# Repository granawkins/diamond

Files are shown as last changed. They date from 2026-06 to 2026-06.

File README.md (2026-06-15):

# Diamond

Diamond is a Raspberry Pi rover named after Neal Stephenson's *The Diamond Age*.
The current build is a four-motor, skid-steer rover in the `rover-v2` printed
body, controlled by an Xbox Wireless Controller.

The abandoned quadruped code and servo UI have been removed. The MG90/SG90 leg
approach was not strong enough once the battery and Pi hardware were installed,
so the project is now wheeled.

## Current Hardware

- Raspberry Pi powered from a Waveshare UPS HAT.
- Four DC gear motors, two on each side.
- Two L298 H-bridge boards, one per side.
- Separate Li-ion/LiPo motor battery with common ground to the Pi.
- Xbox Wireless Controller for live driving.
- `rover-v2` CAD files for the current 3D-printed body.

## Wiring

Do not power the motors from the Pi, UPS HAT, or GPIO header. The Pi and motors
use separate power domains with a shared ground.

```text
                 Brain power domain

  UPS HAT battery
       |
       v
  Waveshare UPS HAT
       |
       | 5V through HAT/header
       v
  Raspberry Pi

                 Motor power domain

  Motor battery positive
       |
       +----> Left L298 +12V / VMS
       |
       +----> Right L298 +12V / VMS

  Motor battery negative
       |
       +----> Left L298 GND
       |
       +----> Right L298 GND
       |
       +----> Raspberry Pi GND, physical pin 6
```

Only the grounds are tied together. Do not tie the motor battery positive rail to
the Pi 5V rail.

Use one L298 board for the left side and one for the right side.

```text
Top view

        front

   left L298 board              right L298 board
   OUT1/OUT2 -> left front      OUT1/OUT2 -> right front
   OUT3/OUT4 -> left rear       OUT3/OUT4 -> right rear

        rear
```

Each L298 board has two channels. Both channels on the same side are driven from
the same three GPIO signals so the front and rear motors on that side always move
together.

## GPIO

BCM numbering is used in code.

| Signal | Pi BCM | Pi physical pin | L298 connection |
|---|---|---|---|
| Left PWM | GPIO12 | pin 32 | Left ENA and ENB |
| Left forward | GPIO5 | pin 29 | Left IN1 and IN3 |
| Left reverse | GPIO6 | pin 31 | Left IN2 and IN4 |
| Right PWM | GPIO13 | pin 33 | Right ENA and ENB |
| Right forward | GPIO20 | pin 38 | Right IN1 and IN3 |
| Right reverse | GPIO16 | pin 36 | Right IN2 and IN4 |
| Ground | GND | pin 6 | Both L298 GND rails |

If the L298 boards have ENA/ENB jumpers installed, remove those jumpers so the Pi
can control speed with PWM. Then connect:

- Pi GPIO12 to both `ENA` and `ENB` on the left L298.
- Pi GPIO13 to both `ENA` and `ENB` on the right L298.

GPIO21 is reserved for I2S speaker audio and should not be used for motor
control.

## Speaker Audio

The MAX98357A I2S amplifier uses the Pi's standard I2S playback pins.

| MAX98357A | Pi BCM | Pi physical pin |
|---|---|---|
| BCLK | GPIO18 | pin 12 |
| LRC / LRCLK | GPIO19 | pin 35 |
| DIN | GPIO21 | pin 40 |
| VIN | 5V | pin 2 or 4 |
| GND | GND | any ground |

The runtime audio device is:

```text
plughw:CARD=MAX98357A,DEV=0
```

If a motor spins backward during testing, swap that motor's two output wires at
the L298 board. Keep the GPIO mapping unchanged.

## Motor Leads

Some gear motors include two heavy motor leads plus four encoder leads. For the
first motor test, only the motor leads connect to the L298 outputs.

Typical color mapping:

| Motor wire | First-test use | Notes |
|---|---|---|
| Red | L298 motor output | Usually motor positive |
| Black | L298 motor output | Usually motor negative |
| Yellow | leave disconnected | Encoder channel A on many motors |
| Green | leave disconnected | Encoder channel B or encoder ground on some variants |
| Blue | leave disconnected | Encoder power or encoder signal on some variants |
| White | leave disconnected | Encoder power, ground, or signal on some variants |

Do not guess the encoder wiring from color alone before powering it. The four
encoder wires are low-current logic wires and should not be connected to L298
outputs or motor power.

## L298 Power Notes

Most L298N modules have a `5V_EN` or `5V enable` jumper:

- With motor battery voltage on the `+12V`/`VMS` terminal, the board usually
  powers its own 5V logic regulator when the jumper is installed.
- Do not connect the L298 board's `5V` terminal to the Pi 5V pin during bring-up.
- If the exact L298 board requires an external 5V logic input, confirm that from
  the board silkscreen or listing before wiring the Pi 5V rail to it.

The Pi's 3.3V GPIO control signals are normally accepted by L298N input pins.

## Wiring Checklist

1. Power the Pi from the Waveshare UPS HAT only.
2. Leave the motor battery disconnected while wiring GPIO.
3. Wire Pi GND pin 6 to both L298 `GND` terminals.
4. Wire the left board GPIO signals.
5. Wire the right board GPIO signals.
6. Wire the four motors to the L298 outputs.
7. Put the rover on blocks so the wheels cannot touch the table or floor.
8. Connect motor battery positive to both L298 `+12V`/`VMS` terminals.
9. Connect motor battery negative to both L298 `GND` terminals.
10. Run `diamond.py` at a conservative speed and verify direction.

## Setup

```bash
python3 -m venv .venv
source .venv/bin/activate
pip install -r requirements.txt
cd webapp
npm install
```

## Web Control

The lightweight web page lives in [index.html](index.html) and is served by
[diamond.py](diamond.py). `diamond.py` is the single hardware owner and also
exposes HTTP endpoints for component testing.

```bash
.venv/bin/python diamond.py --max-speed 1.00
```

By default it listens on `0.0.0.0:3030`.

## Xbox Control

```bash
.venv/bin/python diamond.py --max-speed 1.00
```

The left stick maps to mixed drive: up/down is throttle, left/right is steering.
Put the rover on blocks for first tests. Use a lower `--max-speed` manually if
wiring or direction needs to be re-verified.

## Future Direction

Next major work is vision, audio input/output, and connecting the rover to an LLM,
probably through an API or over Tailscale to a local service running on a desktop
GPU.

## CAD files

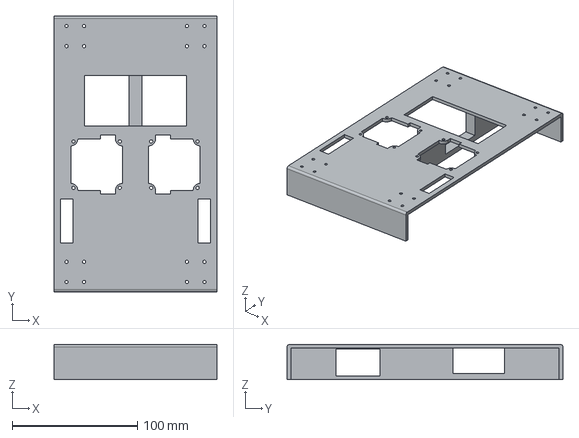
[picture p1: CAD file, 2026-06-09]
rover-v2-Body.3mf.step
130.0 x 220.0 x 28.0 mm

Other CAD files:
rover-v2.FCStd

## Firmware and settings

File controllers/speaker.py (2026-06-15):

import argparse
import math
import tempfile
import subprocess
import wave
from pathlib import Path


"""
Persistent Raspberry Pi setup for the MAX98357A I2S amplifier lives in
/boot/firmware/config.txt:

    dtparam=i2s=on
    dtoverlay=max98357a

After changing those lines, reboot before relying on the speaker after startup.
"""

DEFAULT_DEVICE = "plughw:CARD=MAX98357A,DEV=0"
DEFAULT_FREQUENCY = 880
DEFAULT_SECONDS = 0.25
DEFAULT_VOLUME = 0.10
DEFAULT_RATE = 48000


def list_speakers():
    """Return ALSA playback device listing text from aplay."""

    result = subprocess.run(
        ["aplay", "-l"],
        check=True,
        capture_output=True,
        text=True,
    )
    return result.stdout.strip()


def play_file(path, device=DEFAULT_DEVICE):
    """Play an audio file through the MAX98357A speaker output."""

    audio_path = Path(path)
    subprocess.run(["aplay", "-D", device, str(audio_path)], check=True)


def clamp(value, minimum=0, maximum=1):
    return max(minimum, min(maximum, value))


def write_tone(path, frequency=DEFAULT_FREQUENCY, seconds=DEFAULT_SECONDS, volume=DEFAULT_VOLUME):
    duration = float(seconds)
    if duration <= 0:
        raise ValueError("seconds must be greater than 0")

    amplitude = int(32767 * clamp(float(volume)))
    frames = int(DEFAULT_RATE * duration)

    with wave.open(str(path), "wb") as output:
        output.setnchannels(1)
        output.setsampwidth(2)
        output.setframerate(DEFAULT_RATE)

        for index in range(frames):
            sample = int(amplitude * math.sin(2 * math.pi * frequency * index / DEFAULT_RATE))
            output.writeframesraw(sample.to_bytes(2, "little", signed=True))


def play_tone(
    frequency=DEFAULT_FREQUENCY,
    seconds=DEFAULT_SECONDS,
    volume=DEFAULT_VOLUME,
    device=DEFAULT_DEVICE,
):
    """Play a short sine tone through the MAX98357A speaker output."""

    with tempfile.NamedTemporaryFile(prefix="diamond-tone-", suffix=".wav", delete=True) as file:
        write_tone(file.name, frequency=frequency, seconds=seconds, volume=volume)
        play_file(file.name, device=device)


def parse_args():
    parser = argparse.ArgumentParser(
        description=(
            "Play audio through Diamond's MAX98357A I2S speaker. "
            "Import APIs: controllers.speaker.play_file(), play_tone(), list_speakers()."
        )
    )
    parser.add_argument("file", nargs="?", help="audio file to play with aplay")
    parser.add_argument("--device", default=DEFAULT_DEVICE)
    parser.add_argument("--list", action="store_true", help="list ALSA playback devices")
    parser.add_argument("--tone", action="store_true", help="play a sine tone instead of a file")
    parser.add_argument("--frequency", type=int, default=DEFAULT_FREQUENCY)
    parser.add_argument("--seconds", type=float, default=DEFAULT_SECONDS)
    parser.add_argument("--volume", type=float, default=DEFAULT_VOLUME, help="0.0 to 1.0")
    return parser.parse_args()


def main():
    args = parse_args()

    if args.list:
        print(list_speakers())
    elif args.tone or not args.file:
        play_tone(
            frequency=args.frequency,
            seconds=args.seconds,
            volume=args.volume,
            device=args.device,
        )
    else:
        play_file(args.file, device=args.device)


if __name__ == "__main__":
    main()

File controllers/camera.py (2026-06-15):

import argparse
import subprocess
from pathlib import Path

from controllers.utils import capture_path


DEFAULT_CAMERA = 0
DEFAULT_WIDTH = 1280
DEFAULT_HEIGHT = 720
DEFAULT_TIMEOUT_MS = 1000
DEFAULT_VIDEO_CODEC = "h264"


def default_image_path():
    return capture_path("image", "jpg")


def default_video_path(codec=DEFAULT_VIDEO_CODEC):
    extension = "h264" if codec == "h264" else codec
    return capture_path("video", extension)


def list_cameras():
    """Return rpicam's camera listing text."""

    result = subprocess.run(
        ["rpicam-still", "--list-cameras"],
        check=True,
        capture_output=True,
        text=True,
    )
    return result.stdout.strip()


def capture_image(
    output_path,
    camera=DEFAULT_CAMERA,
    width=DEFAULT_WIDTH,
    height=DEFAULT_HEIGHT,
    timeout_ms=DEFAULT_TIMEOUT_MS,
):
    """Capture a still image from the Raspberry Pi camera."""

    output = Path(output_path)
    output.parent.mkdir(parents=True, exist_ok=True)

    command = [
        "rpicam-still",
        "--camera",
        str(camera),
        "--width",
        str(int(width)),
        "--height",
        str(int(height)),
        "--timeout",
        str(int(timeout_ms)),
        "--output",
        str(output),
        "--nopreview",
    ]
    subprocess.run(command, check=True, timeout=(int(timeout_ms) / 1000) + 10)
    return output


def record_video(
    output_path,
    seconds=5,
    camera=DEFAULT_CAMERA,
    width=DEFAULT_WIDTH,
    height=DEFAULT_HEIGHT,
    codec=DEFAULT_VIDEO_CODEC,
):
    """Record video from the Raspberry Pi camera."""

    duration_ms = int(float(seconds) * 1000)
    if duration_ms <= 0:
        raise ValueError("seconds must be greater than 0")

    output = Path(output_path)
    output.parent.mkdir(parents=True, exist_ok=True)

    command = [
        "rpicam-vid",
        "--camera",
        str(camera),
        "--width",
        str(int(width)),
        "--height",
        str(int(height)),
        "--timeout",
        str(duration_ms),
        "--codec",
        codec,
        "--output",
        str(output),
        "--nopreview",
    ]
    subprocess.run(command, check=True, timeout=(duration_ms / 1000) + 10)
    return output


def parse_args():
    parser = argparse.ArgumentParser(
        description=(
            "Capture images or video from Diamond's Raspberry Pi camera. "
            "Import APIs: controllers.camera.capture_image(), record_video(), list_cameras()."
        )
    )
    parser.add_argument("output", nargs="?")
    parser.add_argument("--list", action="store_true", help="list detected cameras")
    parser.add_argument("--video", action="store_true", help="record video instead of a still image")
    parser.add_argument("--seconds", type=float, default=5, help="video duration")
    parser.add_argument("--camera", type=int, default=DEFAULT_CAMERA)
    parser.add_argument("--width", type=int, default=DEFAULT_WIDTH)
    parser.add_argument("--height", type=int, default=DEFAULT_HEIGHT)
    parser.add_argument("--timeout-ms", type=int, default=DEFAULT_TIMEOUT_MS, help="still capture warmup")
    parser.add_argument("--codec", default=DEFAULT_VIDEO_CODEC, help="video codec for rpicam-vid")
    return parser.parse_args()


def main():
    args = parse_args()

    if args.list:
        print(list_cameras())
        return

    if args.video:
        output_path = args.output or default_video_path(args.codec)
        output = record_video(
            output_path,
            seconds=args.seconds,
            camera=args.camera,
            width=args.width,
            height=args.height,
            codec=args.codec,
        )
        print(f"Recorded {args.seconds:g}s video to {output}")
    else:
        output_path = args.output or default_image_path()
        output = capture_image(
            output_path,
            camera=args.camera,
            width=args.width,
            height=args.height,
            timeout_ms=args.timeout_ms,
        )
        print(f"Captured image to {output}")


if __name__ == "__main__":
    main()

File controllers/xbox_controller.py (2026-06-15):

import glob
import os
import select
import subprocess
from dataclasses import dataclass, field
from time import sleep

from evdev import InputDevice, ecodes


DEFAULT_DEVICE = "/dev/input/event5"
DEFAULT_CONTROLLER_MAC = "40:8E:2C:4A:2D:2E"
LEFT_STICK_X = ecodes.ABS_X
LEFT_STICK_Y = ecodes.ABS_Y


@dataclass
class ControllerState:
    x: float = 0
    y: float = 0
    buttons: list[str] = field(default_factory=list)
    changed: bool = False


def normalize_axis(value, absinfo):
    center = (absinfo.min + absinfo.max) / 2
    span = (absinfo.max - absinfo.min) / 2

    if span <= 0:
        return 0

    return max(-1, min(1, (value - center) / span))


def apply_deadzone(value, deadzone):
    if abs(value) < deadzone:
        return 0

    scaled = (abs(value) - deadzone) / (1 - deadzone)
    return scaled if value > 0 else -scaled


def find_device(path=DEFAULT_DEVICE):
    if os.path.exists(path) and is_drive_device(path):
        return path

    for candidate in sorted(glob.glob("/dev/input/event*")):
        if is_drive_device(candidate):
            return candidate

    return None


def is_drive_device(path):
    try:
        device = InputDevice(path)
        device.absinfo(LEFT_STICK_X)
        device.absinfo(LEFT_STICK_Y)
    except OSError:
        return False

    return "xbox" in device.name.lower()


def connect_controller(mac=DEFAULT_CONTROLLER_MAC):
    try:
        subprocess.run(
            ["bluetoothctl", "connect", mac],
            check=False,
            capture_output=True,
            text=True,
            timeout=8,
        )
    except (OSError, subprocess.TimeoutExpired) as error:
        print(f"Bluetooth connect attempt failed: {error}", flush=True)


def connect_xbox_controller(
    device_path=DEFAULT_DEVICE,
    controller_mac=DEFAULT_CONTROLLER_MAC,
    deadzone=0.08,
):
    try:
        controller = XboxController(
            device_path=device_path,
            controller_mac=controller_mac,
            deadzone=deadzone,
            wait=False,
        )
    except (FileNotFoundError, OSError):
        connect_controller(controller_mac)
        raise

    print(f"Connected to {controller.name} at {controller.device_path}", flush=True)
    print("Left stick drives live. Release to center/stop.", flush=True)
    return controller


def wait_for_device(path=DEFAULT_DEVICE, controller_mac=DEFAULT_CONTROLLER_MAC):
    while True:
        device_path = find_device(path)

        if device_path:
            return device_path

        print(
            f"Waiting for Xbox controller {controller_mac}; trying Bluetooth connect",
            flush=True,
        )
        connect_controller(controller_mac)
        sleep(5)


class XboxController:
    """Xbox controller reader that owns connection and event polling."""

    def __init__(
        self,
        device_path=DEFAULT_DEVICE,
        controller_mac=DEFAULT_CONTROLLER_MAC,
        deadzone=0.08,
        wait=True,
    ):
        if not 0 <= deadzone < 1:
            raise ValueError("deadzone must be at least 0 and less than 1")

        self.device_path = (
            wait_for_device(device_path, controller_mac)
            if wait
            else find_device(device_path)
        )
        if not self.device_path:
            raise FileNotFoundError("Xbox controller drive device not found")

        self.device = InputDevice(self.device_path)
        self.deadzone = deadzone
        self.x_value = self.device.absinfo(LEFT_STICK_X).value
        self.y_value = self.device.absinfo(LEFT_STICK_Y).value
        self.state = self._state(changed=True)

    @property
    def name(self):
        return self.device.name

    def fileno(self):
        return self.device.fd

    def _state(self, buttons=None, changed=False):
        x_info = self.device.absinfo(LEFT_STICK_X)
        y_info = self.device.absinfo(LEFT_STICK_Y)
        x = apply_deadzone(normalize_axis(self.x_value, x_info), self.deadzone)
        y = apply_deadzone(-normalize_axis(self.y_value, y_info), self.deadzone)
        return ControllerState(x=x, y=y, buttons=buttons or [], changed=changed)

    def poll(self, timeout=0):
        readable, _, _ = select.select([self.device.fd], [], [], timeout)

        if not readable:
            self.state = self._state()
            return self.state

        changed = False
        buttons = []

        for event in self.device.read():
            if event.type == ecodes.EV_ABS:
                if event.code == LEFT_STICK_X:
                    self.x_value = event.value
                    changed = True
                elif event.code == LEFT_STICK_Y:
                    self.y_value = event.value
                    changed = True
            elif event.type == ecodes.EV_KEY and event.value:
                buttons.append(ecodes.KEY.get(event.code, str(event.code)))
                changed = True

        self.state = self._state(buttons=buttons, changed=changed)
        return self.state

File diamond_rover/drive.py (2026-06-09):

PINS = {
    "left": {"forward": 5, "reverse": 6, "enable": 12},
    "right": {"forward": 20, "reverse": 21, "enable": 13},
}


def clamp(value, minimum=-1, maximum=1):
    return max(minimum, min(maximum, value))


def validate_power(value, name="power"):
    power = float(value)
    if not -1 <= power <= 1:
        raise ValueError(f"{name} must be between -1 and 1")
    return power


def validate_speed(value, name="speed"):
    speed = float(value)
    if not 0 <= speed <= 1:
        raise ValueError(f"{name} must be between 0 and 1")
    return speed


def validate_seconds(value, maximum=5):
    seconds = float(value)
    if not 0 < seconds <= maximum:
        raise ValueError(f"seconds must be greater than 0 and no more than {maximum:g}")
    return seconds


def mix_differential(throttle, steering, max_speed=1):
    max_speed = validate_speed(max_speed, "max_speed")
    raw_left = float(throttle) + float(steering)
    raw_right = float(throttle) - float(steering)
    scale = max(1, abs(raw_left), abs(raw_right))

    return (
        clamp((raw_left / scale) * max_speed),
        clamp((raw_right / scale) * max_speed),
    )


class MotorSide:
    def __init__(self, forward_pin, reverse_pin, enable_pin):
        from gpiozero import Motor, PWMOutputDevice

        self.motor = Motor(forward=forward_pin, backward=reverse_pin)
        self.enable = PWMOutputDevice(enable_pin)
        self.power = None

    def move(self, power):
        power = clamp(float(power))

        if self.power is not None and abs(power - self.power) < 0.01:
            return

        self.power = power
        self.enable.value = abs(power)

        if power > 0:
            self.motor.forward()
        elif power < 0:
            self.motor.backward()
        else:
            self.motor.stop()

    def stop(self):
        self.power = 0
        self.motor.stop()
        self.enable.value = 0


class RoverDrive:
    def __init__(self, pins=PINS):
        self.left = MotorSide(
            forward_pin=pins["left"]["forward"],
            reverse_pin=pins["left"]["reverse"],
            enable_pin=pins["left"]["enable"],
        )
        self.right = MotorSide(
            forward_pin=pins["right"]["forward"],
            reverse_pin=pins["right"]["reverse"],
            enable_pin=pins["right"]["enable"],
        )

    def move(self, left_power, right_power):
        self.left.move(validate_power(left_power, "left"))
        self.right.move(validate_power(right_power, "right"))

    def move_side(self, side, power):
        if side not in ("left", "right"):
            raise ValueError("side must be left or right")

        getattr(self, side).move(validate_power(power, side))

    def stop(self):
        self.left.stop()
        self.right.stop()

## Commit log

2025-10-11 four legs
2025-10-23 remove reset servo
2025-10-24 battery percentage
2025-10-25 servo calibration
2025-10-25 apply calibration
2025-10-26 leg backend
2025-10-26 leg frontend
2026-06-09 Simplify repo around rover control
    [rover-v2-Body.3mf.step, rover-v2.FCStd]
